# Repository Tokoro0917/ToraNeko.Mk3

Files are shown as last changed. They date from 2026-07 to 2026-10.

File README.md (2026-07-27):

# ToraNeko.Mk3

マイクロマウス（ハーフサイズクラス）ToraNeko の3代目機体（Mk3）のソフトウェア・ハードウェア（回路）・機構設計をまとめて管理するリポジトリです。
KOGUMA（クラシックサイズ機）とは別系譜の機体です。前身の KOGUMA.Mk3 系リポジトリはソフトウェアのみを対象としていましたが、本リポジトリでは
回路図・基板データ・配線資料なども含めて一元管理し、ソフトとハードの変更履歴を紐付けて追跡できるようにします。

ロボットの詳細な概要・仕様は [docs/overview.md](./docs/overview.md) を参照してください。

## ディレクトリ構成

```
.
├── software/    # マイコン・PC側ソフトウェア一式
├── hardware/    # 回路図・基板データ（KiCadプロジェクト）・BOM
├── mechanical/  # 機構部品・3Dモデル・図面
└── docs/        # 配線図、仕様書、設計メモ、議事録などのドキュメント
```

各ディレクトリの詳細は、それぞれの README.md を参照してください。

## 設計データの管理方針

- 回路・基板設計は [KiCad](https://www.kicad.org/) を使用します。プロジェクト一式は `hardware/kicad/` 以下にサブシステムごとのディレクトリを作って格納します。
- ソフトウェアは `software/` 以下にサブシステム・マイコンボードごとのディレクトリを作って格納します。
- 既存の KOGUMA.Mk3 のソフトウェア資産は、必要になったタイミングで個別に移行するかを検討します（現時点では未移行）。

## ライセンス

このリポジトリは [MIT License](./LICENSE) の下で公開されます。

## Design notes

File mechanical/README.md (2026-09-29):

# mechanical/

機構部品・筐体・3Dモデル・図面など、機械設計に関するデータを格納します。

## 構成の考え方

パーツ・アセンブリ単位、もしくはサブシステム単位でディレクトリを分けて配置してください。例:

```
mechanical/
├── frame/         # 車体・フレーム
├── drive-unit/    # 駆動系機構
└── exported/      # 発注・共有用に書き出したSTEP/STL等
```

`jigs/` には製作用の治具を置いています（[エンコーダはんだ付け治具](./jigs/encoder_solder_jig/)）。

CADツールは **Fusion 360** を使用しています。

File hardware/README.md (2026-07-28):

# hardware/

回路・基板の設計データを格納します。設計ツールは [KiCad](https://www.kicad.org/) を使用します。

## 構成の考え方

基板（プロジェクト）ごとにディレクトリを分けて `hardware/kicad/` 以下に配置してください。例:

```
hardware/
├── kicad/
│   ├── TORANEKO.Mk3/
│   ├── motor-driver-board/
│   └── sensor-board/
└── datasheets/    # 使用部品のデータシートPDF（型番横断で一元管理）
```

使用部品のデータシートは [datasheets/](./datasheets/) にまとめています。

各プロジェクトディレクトリには、KiCad のプロジェクト一式（`.kicad_pro` / `.kicad_sch` / `.kicad_pcb` など）に加えて、
以下も一緒に管理することを推奨します。

- `BOM.csv`（部品表）
- `README.md`（基板の役割、電源電圧、コネクタ・ピンアサインの概要）
- 発注用に出力したガーバー・ドリルデータ（`fab-output/` 等のサブディレクトリにまとめる）

## 運用メモ

- 基板データが大きくなってきた場合は Git LFS の導入を検討します（現時点では未導入）。
- 回路変更とそれに対応するソフトウェア変更は、可能な限り同じコミット/PRで紐付けてください。

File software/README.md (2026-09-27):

# software/

ToraNeko.Mk3 のソフトウェア一式を格納します。

## 構成の考え方

サブシステムやマイコンボードごとにディレクトリを分けて配置してください。例:

```
software/
├── main-controller/   # メイン基板（例: STM32等）のファームウェア
├── motor-driver/      # モータドライバ基板のファームウェア
└── pc-tools/          # デバッグ・調整用のPC側ツール
```

## 既存資産について

KOGUMA.MkIIl のファームウェアを参照用として `reference/koguma-mkiil/` に取り込みました。メイン基板のファームウェアは、これを参照しながら `main-controller/` に一つずつ実装していきます。

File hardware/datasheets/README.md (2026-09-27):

# hardware/datasheets/

使用部品のデータシートPDFを格納する場所です。リンク切れやメーカーサイトの仕様変更に備えて、
実際に使う部品のデータシートはPDFの実体をここに置いておきます。

## アップロード方法

1. メーカーまたは販売代理店（DigiKey/Mouser/RSなど）のサイトからPDFをダウンロードする
2. ファイル名は `<型番>.pdf` とする（例: `NCR321PAS.pdf`）
3. GitHubのWeb UIでこのディレクトリにドラッグ＆ドロップでアップロード、またはローカルにcloneしてpushする

## 部品一覧

| 型番 | 用途 | メーカー | 参考リンク | PDF |
|---|---|---|---|---|
| STM32F411CEU6 | MCU | STMicroelectronics | https://www.st.com/en/microcontrollers-microprocessors/stm32f411ce.html | 未アップロード |
| MP6551 | モータドライバ | Monolithic Power Systems | https://www.monolithicpower.com/en/mp6551.html | 未アップロード |
| NFP-D0812-1-3.7 | ブラシ付きDCモータ | - | - | 未アップロード |
| LSM6DSRXTR | IMU（ジャイロ/加速度） | STMicroelectronics | https://www.st.com/en/mems-and-sensors/lsm6dsrx.html | 未アップロード |
| AS5047P | 磁気式エンコーダ | ams OSRAM | https://ams-osram.com/products/sensor-solutions/position-sensors/ams-as5047p-high-resolution-position-sensor | 未アップロード |
| LTR-209 | 壁センサ受光（フォトトランジスタ） | Lite-On | - | 未アップロード |
| OSI5FU3A11C | 壁センサ発光（IR LED、3mm、940nm） | Optosupply | https://www.optosupply.com/uppic/20241121109582.pdf | [OSI5FU3A11C.pdf](OSI5FU3A11C.pdf)（VER A.0） |
| NCR321PAS | 壁センサLEDドライバ（定電流） | Nexperia | https://assets.nexperia.com/documents/data-sheet/NCR320PAS_NCR321PAS.pdf | [NCR321PAS.pdf](NCR321PAS.pdf)（NCR320PAS と共通、Rev.1 2020-05-13） |
| LXDC55FAAA-203 | 3.3Vレギュレータ | - | - | 未アップロード |

「参考リンク」が空欄の部品は型番からの検索が必要です。分かる方はこのテーブルに追記してください。

## 備考

- この実行環境（Claude Code on the web）はアウトバウンド通信が許可ドメインのみに制限されているため、
  Claude自身がこれらのPDFを取得してアップロードすることはできません。人手でのアップロードが必要です。

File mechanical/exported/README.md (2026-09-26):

# mechanical/exported/

Fusion 360 から書き出した共有用データ（STEP等）を置いています。

## TORANEKO.Mk3_v36.step

機体全体のアセンブリ（Fusion 360 のトップコンポーネント「全体」v36、単位mm）。

主な構成部品:

| 区分 | 部品 |
|---|---|
| 基板 | 基板（メイン基板）、上部固定基板、エンコーダ基板 × 2 |
| 駆動系 | NFP-D0812 モータ × 2、モータマウント × 2、ピニオンギア m0.3 11T × 2、平歯車 m0.3 41T × 2（減速比 41/11 ≒ 3.73）、ベアリング LF-630 × 4、3×6 平行ピン × 2 |
| 足回り | ホイール × 2、ミニッツタイヤ × 2 |
| エンコーダ | 3mm 磁石 × 2（エンコーダ基板上の AS5047P で検出） |
| 壁センサ | センサホルダ × 4、3mm 砲丸LED × 4 |
| 吸引 | 吸引ファン Φ30（アクリル）、吸引ファンモータマウント |
| 電源 | ヤシの木バッテリー 100mAh × 2 |
| その他 | 支柱 |

基板外形のDXFは `hardware/kicad/TORANEKO.Mk3/` にあります。

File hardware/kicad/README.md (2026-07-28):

# hardware/kicad/

KiCad プロジェクトを基板（サブシステム）ごとにディレクトリを分けて配置してください。

例:

```
kicad/
├── TORANEKO.Mk3/
│   ├── TORANEKO.Mk3.kicad_pro
│   ├── TORANEKO.Mk3.kicad_sch
│   ├── TORANEKO.Mk3.kicad_pcb
│   ├── BOM.csv
│   └── README.md
└── motor-driver-board/
    └── ...
```

## 現在のプロジェクト

- [TORANEKO.Mk3/](./TORANEKO.Mk3/) — メイン基板（1枚基板・全機能統合）。KiCadプロジェクト作成済み（現状は空、これから回路図を起こす）。機能ブロック・ペリフェラル割り当て案・BOMドラフトも同ディレクトリに格納。

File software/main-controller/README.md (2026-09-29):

# main-controller

ToraNeko.Mk3 メイン基板（STM32F411CEU6）のファームウェアです。

KOGUMA.MkIIl のコード（[../reference/koguma-mkiil/](../reference/koguma-mkiil/)）を参照しつつ、機能ごとに内容を確認しながら一つずつ実装していきます。
確認・実装が済んだものだけをこのディレクトリに置きます。

- [PIN_REQUIREMENTS.md](PIN_REQUIREMENTS.md): 確定したピン割り当て（回路図から抽出）と、KOGUMA との違い
- [CUBEMX_SETUP.md](CUBEMX_SETUP.md): CubeMX（`.ioc`）の設定値（ステップ0）

## 決定事項

| 項目 | 決定 | 理由・補足 |
|---|---|---|
| 書き込み・デバッグ | STLINK-V3MODS（SWD） | SWDIO=PA13, SWCLK=PA14, NRST。SWO（PB3）は任意 |
| PCとの通信・printf | UART → STLINK-V3MODS の仮想COMポート | 書き込みとログがケーブル1本で済む。**USBは使わない**（PA11/PA12 を他用途に回せる） |
| UART | USART1（PA9 TX / PA10 RX）を推奨 | APB2 側なので高速化しやすい。PA2/PA3（USART2）は ADC 入力と取り合いになるため避ける |
| 開発環境 | STM32CubeIDE | KOGUMA と同じ。ピン・クロック設定は `.ioc`（CubeMX）で管理 |
| ライブラリ | STM32 HAL | 1kHz 割り込み内で重い箇所は、必要になったら LL/レジスタ直接に置き換える |
| プロジェクト名 | `TORANEKO.Mk3` | KiCad プロジェクトと揃える |
| クロック | HSE 水晶 10MHz → SYSCLK 100MHz | PLL: M=5, N=200, P=4（VCO 400MHz）。APB1=50MHz、APB2=100MHz、タイマークロックは全て100MHz。USBを使わないので48MHzは不要 |
| 制御周期 | **2kHz**（`config/robot_params.h` の `CTRL_FREQ_HZ` で変更可能にする） | 処理時間の見積りは CPU 使用率 約10〜18%。実機で余裕を測り、余裕があれば 4kHz（壁センサは 2kHz のまま）に上げる。PID ゲイン等は周期から換算する作りにする |
| 制御周期のタイマー | TIM11 | ピンを使わない内部タイマー |
| 壁センサの点灯・測定の順番制御 | TIM3 で ADC を起動し、DMA 完了割り込みで次の LED に進める連鎖方式 | CPU を待たせずに 4 組を毎周期測定できる（2組ずつ同時点灯なので連鎖全体で約 100µs）。詳細はステップ6 |
| 処理時間計測・µs 待ち | TIM5（32bit）を 1MHz でフリーラン | 制御割り込みの開始・終了時刻を記録して CPU 使用率を常に確認できるようにする |
| ms 単位の待ち | SysTick（`HAL_GetTick()`） | KOGUMA の「共通カウンタを 0 に戻す `wait_ms`」はやめる |
| 割り込み優先度 | 壁センサの連鎖（ADC の DMA）> 制御周期（TIM11）> ログ送信（USART の DMA） | 制御処理が長引いてもセンサ測定が遅れないようにする |
| ファイル構成・命名規則 | 下記「ファイル構成」「命名規則」の通り | 生成コードと自作コードを分離し、自作コードは層ごとにフォルダ分け |

## ファイル構成

```
software/main-controller/
├── README.md                     決定事項・ファイル構成・実装ステップ（このファイル）
├── PIN_REQUIREMENTS.md           ピン割り当ての論点
│
└── TORANEKO.Mk3/                 CubeIDE プロジェクト
    ├── TORANEKO.Mk3.ioc          CubeMX 設定（ピン・クロック・周辺機能）
    ├── .project / .cproject      CubeIDE のプロジェクト設定（生成）
    ├── STM32F411CEUX_FLASH.ld    リンカスクリプト（生成）
    │
    ├── Core/                     ── CubeMX が生成。USER CODE 欄以外は編集しない
    │   ├── Inc/
    │   │   ├── main.h            ピン名の定義（.ioc のラベルから生成）
    │   │   ├── adc.h  dma.h  gpio.h  spi.h  tim.h  usart.h
    │   │   ├── stm32f4xx_it.h
    │   │   └── stm32f4xx_hal_conf.h
    │   ├── Src/
    │   │   ├── main.c            初期化のあと app_init() / app_loop() を呼ぶだけ
    │   │   ├── adc.c  dma.c  gpio.c  spi.c  tim.c  usart.c   周辺機能の初期化
    │   │   ├── stm32f4xx_it.c    割り込みの入口（処理は App 側を呼ぶだけ）
    │   │   ├── stm32f4xx_hal_msp.c
    │   │   ├── system_stm32f4xx.c
    │   │   ├── syscalls.c        printf の出力先を UART に向ける
    │   │   └── sysmem.c
    │   └── Startup/
    │       └── startup_stm32f411ceux.s
    │
    ├── Drivers/                  ── HAL / CMSIS（生成・編集しない）
    │
    ├── App/                      ── 自作コードはすべてここ
    │   ├── app.c / app.h         app_init()、app_loop()。全体の入口
    │   │
    │   ├── config/               機体の定数
    │   │   ├── robot_params.h    タイヤ径、ギア比、トレッド幅、制御周期など
    │   │   └── ctrl_gains.h      PID ゲイン、フィードフォワード係数
    │   │
    │   ├── drv/                  ハードに直接触れる層（HAL を呼ぶのはここだけ）
    │   │   ├── encoder.c/.h      AS5047P ×2：角度の読み取り
    │   │   ├── imu.c/.h          LSM6DSR：角速度・加速度の読み取り
    │   │   ├── motor.c/.h        MP6551 ×2：PWM の出力（電圧を指定）
    │   │   ├── wall.c/.h         壁センサ：LED を2組ずつ点灯し、AD 値を読む
    │   │   ├── battery.c/.h      バッテリ電圧の読み取り
    │   │   ├── fan.c/.h          吸引ファンの PWM
    │   │   ├── led.c/.h          UI 用 LED
    │   │   ├── buzzer.c/.h       ブザー
    │   │   └── uart.c/.h         ログ送信（DMA 送信・リングバッファ）
    │   │
    │   ├── ctrl/                 制御
    │   │   ├── odometry.c/.h     エンコーダと IMU から速度・距離・角度を求める
    │   │   ├── pid.c/.h          汎用の PID 計算
    │   │   ├── trajectory.c/.h   台形加減速などの目標速度の生成
    │   │   ├── wall_ctrl.c/.h    壁のあり・なし判定、壁に沿った姿勢の補正
    │   │   └── run.c/.h          直進・スラローム・斜めなどの動作
    │   │
    │   ├── maze/                 迷路（HAL に依存しない。PC でテストできる）
    │   │   ├── maze_map.c/.h     壁の情報の保持・更新・保存
    │   │   ├── search.c/.h       足立法・歩数マップ・行き止まり潰し
    │   │   └── path.c/.h         最短経路（ダイクストラ）と、経路の圧縮・斜めへの変換
    │   │
    │   └── sys/                  全体の管理
    │       ├── scheduler.c/.h    1kHz の周期処理（センサ → 制御 → 出力の順に呼ぶ）
    │       ├── mode.c/.h         走行モードの選択と実行
    │       ├── ui.c/.h           モード選択の操作、LED・ブザーでの通知
    │       ├── log.c/.h          走行ログの記録と吸い出し
    │       ├── failsafe.c/.h     異常の検知（衝突、電圧低下など）と停止
    │       └── flash.c/.h        迷路・パラメータの Flash への保存
    │
    └── test/                     ── PC 上で動かすテスト（CI で実行）
        ├── test_maze.c           迷路探索・最短経路のテスト
        └── Makefile
```

### 層の依存関係

```
sys  →  ctrl / maze  →  drv  →  HAL（Core/, Drivers/）
```

- 呼び出しは上の層から下の層への一方向のみ。`drv` から `ctrl` を呼ぶような逆向きの呼び出しはしない
- HAL を直接呼ぶのは `drv/` と `sys/scheduler.c`（タイマー割り込みの起動）だけ
- `maze/` は `drv` も HAL も使わない。PC 上でそのままテストできる
- `Core/` 側の生成コードには、USER CODE 欄に `App/` の関数呼び出しを1行書くだけにする（CubeMX で再生成しても自作コードが消えないように）

## 命名規則

| 対象 | 規則 | 例 |
|---|---|---|
| ファイル名 | 小文字＋アンダースコア。層はフォルダで表し、ファイル名には付けない | `drv/encoder.c`, `ctrl/pid.c` |
| 関数名 | `モジュール名_動詞_目的語`（小文字＋アンダースコア） | `encoder_read_angle()`, `motor_set_voltage()` |
| 型名 | 小文字＋アンダースコア＋`_t` | `pid_ctrl_t`, `odometry_state_t`（`pid_t` は標準ライブラリと衝突するので使わない） |
| ファイルをまたぐ変数 | `g_` を付ける（なるべく使わず、関数経由で受け渡す） | `g_maze_map` |
| ファイル内だけの変数・関数 | `static` を付ける | `static float s_prev_error;` |
| 定数・マクロ | 大文字＋アンダースコア | `MAZE_SIZE`, `CTRL_PERIOD_S` |
| インクルードガード | `ファイルパスを大文字に_H` | `DRV_ENCODER_H` |

## 実装の進め方

各ステップで「KOGUMA の該当コードを読む → ToraNeko で変える点を決める → 実装 → 実機/PCで確認」を行います。

| # | 内容 | 作るファイル | KOGUMA側の対応ファイル | 状態 |
|---|---|---|---|---|
| 0 | F411 用の空プロジェクト作成（CubeIDE、クロック設定） | `.ioc`, `Core/`, `App/app.c` | `KOGUMA.MkIIl.ioc` | 設定値決定済み（[CUBEMX_SETUP.md](CUBEMX_SETUP.md)）。プロジェクト作成待ち |
| 1 | LED点灯とシリアル出力（printf） | `drv/led.c`, `drv/uart.c` | `UI.c`, `syscalls.c` | 未着手 |
| 2 | 2kHz 制御周期割り込み | `sys/scheduler.c` | `PL_timer.c` | 未着手 |
| 3 | エンコーダ読み取り（AS5047P） | `drv/encoder.c` | `PL_encoder.c` | 未着手 |
| 4 | IMU 読み取り（LSM6DSR） | `drv/imu.c` | `lsm6dsr.c` | 未着手 |
| 5 | モータ PWM | `drv/motor.c` | `motor.c`（出力部分） | 未着手 |
| 6 | 壁センサ（2組ずつ点灯） | `drv/wall.c`, `ctrl/wall_ctrl.c` | `PL_sensor.c`, `Wallsensor.c` | 未着手 |
| 7 | 速度・角度制御（PID、フィードフォワード） | `ctrl/odometry.c`, `ctrl/pid.c`, `ctrl/trajectory.c`, `ctrl/run.c` | `motor.c`, `Move.c` | 未着手 |
| 8 | 迷路探索と最短経路 | `maze/*`, `test/` | `Maze.c` | 未着手（PCでテスト可） |
| 9 | 走行モード、ログ、フェイルセーフ、保存 | `sys/mode.c`, `sys/ui.c`, `sys/log.c`, `sys/failsafe.c`, `sys/flash.c` | `main.c`, `UI.c`, `LOG.c`, `Failsafe.c` | 未着手 |

### KOGUMA のファイルとの対応

| KOGUMA | ToraNeko |
|---|---|
| `PL_encoder.c` | `drv/encoder.c` |
| `lsm6dsr.c` | `drv/imu.c` |
| `PL_sensor.c` | `drv/wall.c`（LED点灯・AD読み取り）、`drv/battery.c` |
| `Wallsensor.c` | `ctrl/wall_ctrl.c` |
| `motor.c` | `drv/motor.c`（PWM出力）、`ctrl/pid.c`、`ctrl/odometry.c`、`drv/fan.c` |
| `Move.c` | `ctrl/trajectory.c`、`ctrl/run.c` |
| `Maze.c` | `maze/maze_map.c`、`maze/search.c`、`maze/path.c` |
| `PL_timer.c` | `sys/scheduler.c` |
| `main.c`（モード選択部分） | `sys/mode.c` |
| `UI.c` | `sys/ui.c`、`drv/led.c`、`drv/buzzer.c` |
| `LOG.c` | `sys/log.c` |
| `Failsafe.c` | `sys/failsafe.c` |
| `Define.h` | `config/robot_params.h`、`config/ctrl_gains.h` |

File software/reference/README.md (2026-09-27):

# reference/

参照用に取り込んだ過去の機体のソフトウェアです。**ここのコードは編集しません。**
ToraNeko.Mk3 用の実装は `../main-controller/` で行います。

| ディレクトリ | 元リポジトリ | コミット | 備考 |
|---|---|---|---|
| `koguma-mkiil/` | [Tokoro0917/KOGUMA.MkIIl](https://github.com/Tokoro0917/KOGUMA.MkIIl) | `e456da38832444fc30eb78e9e4e20f32978636c6`（2026-09-25） | STM32F446RE 向け。旧版 `KOGUMA.MkII/` と `.github/` は除外 |

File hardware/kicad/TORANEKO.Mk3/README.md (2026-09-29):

# TORANEKO.Mk3

ToraNeko.Mk3 のメイン基板（1枚基板・全機能統合、基板一体型シャーシ）のKiCadプロジェクトです。

KiCadプロジェクト本体（`TORANEKO.Mk3.kicad_pro` / `.kicad_sch` / `.kicad_pcb`）を作成済みです（現状は空、これから回路図を起こしていきます）。
このディレクトリには、実際に回路図を起こす前に固めておいた機能ブロック構成・ペリフェラル割り当て案・BOMドラフトも一緒に置いています。

## 機能ブロック

| ブロック | 内容 |
|---|---|
| MCU | STM32F411CEU6 |
| モータドライバ | MP6551 × 2（左モータ用・右モータ用） |
| モータ | NFP-D0812-1-3.7（ブラシ付きDC）× 2 |
| エンコーダ | AS5047P（磁気式）× 2、左右モータ軸に取り付け |
| IMU | LSM6DSRXTR |
| 壁センサ | 反射型IR。受光: LTR-209、発光: OSI5FU3A11C、LEDドライバ: **NCR321PAS**（定電流・PWM対応）。前方斜め左右2組・側面左右2組の計4組 |
| 吸引ファン | サクションファン × 1（型番未定）。NチャネルMOSFETによるローサイドPWM駆動 |
| 電源 | 2セルLiPo入力 → MCU/センサ用3.3V系（**LXDC55FAAA-203**）、モータドライバ（MP6551）はLiPo直結 |
| デバッグ/書き込み | STLINK-V3MODS（SWD＋仮想COMポート）。USBは使わない |
| クロック | HSE 水晶 10MHz → SYSCLK 100MHz |

## ペリフェラル割り当て案（STM32F411CEU6）

正確なピン番号はKiCadで回路図を起こす際にデータシート（UFQFPN48パッケージ）で確定してください。
ここではどのペリフェラルをどのブロックに割り当てるかの方針のみ示します。

- **SPIバス（IMU・エンコーダ用）**: LSM6DSRXTR、AS5047P × 2 は共通SPIバス上にCS（チップセレクト）を分けて接続する案。SPIバスを分割するかは配線の都合で判断。
- **PWM（モータ駆動用）**: MP6551 × 2 に対し、1モータあたり2本（IN1/IN2、もしくはPWM+DIR）を想定。TIM1などの高機能タイマーを優先的に割り当てる。
- **ADC（壁センサ用）**: LTR-209（受光）× 4組ぶんでADC 4チャンネル（PA3〜PA6）を使用。OSI5FU3A11C（発光）側は **NCR321PAS**（LED 1個につき1個）の VEN を GPIO 2本で2組ずつ駆動する（組A: PB0、組B: PA7）
- **PWM（吸引ファン用）**: MOSFETゲート駆動用に1チャンネル。モータ駆動用タイマーとは別チャンネルを割り当てる。
- **UART（ログ出力）**: USART1（PA9 TX / PA10 RX）を STLINK-V3MODS の仮想COMポートに接続する案。USBは使わないので PA11/PA12 は他用途に使える。
- **SWD**: STLINK-V3MODS での書き込み・デバッグ用に PA13（SWDIO）/ PA14（SWCLK）/ NRST を確保。SWO（PB3）は任意。

## 電源設計メモ

- 入力: 2セルLiPo（7.4V公称、満充電8.4V程度）
- MCU/センサ系: 3.3Vへ降圧、**LXDC55FAAA-203** を使用
- 壁センサLEDドライバ（NCR321PAS）: **3.3V系から給電（決定）**。センサ周りにバッテリ電圧（変動する電圧）を持ち込まないため。LED 1個につき NCR321PAS 1個、**ピーク約 155mA** のパルス点灯。回路は下記「壁センサ発光回路」を参照
- モータ系: LiPoをレギュレータを介さず**MP6551に直結**（MP6551の定格電圧範囲内であることを確認済みとして進める）
- 吸引ファン系: LiPoから供給、MOSFETでPWM制御（レギュレータを挟むかはファン選定後に確定）

## 壁センサ発光回路

LED 1個につき NCR321PAS 1個（×4組）。発光制御の GPIO は2本で、1本の GPIO で2個の VEN を同時に駆動する（組A: PB0 → IC3/D7 と IC8/D9、組B: PA7 → IC4/D8 と IC9/D10）。組み合わせは **組A = 左前向き＋右向き、組B = 右前向き＋左向き**。横向きの2組は光軸が機体中央で交差する（クロス配置）が、別の組なので同時には点かない。同時に点く2組は向きが反対なので干渉しにくい。ただし同じ組の2個は機体の同じ側に並ぶ（右向きは左側に付いて右を向くため）ので、LED からの光が隣の受光素子に直接入らないよう、センサホルダで遮光する。

2個同時点灯なのでピーク電流は約 310mA（155mA × 2）。大容量コンデンサの電圧降下も2倍になり、NCR321PAS の電圧余裕は最悪で 1.4V をわずかに下回る見込み。足りない場合は電流が少し下がる（暗くなる）だけなので、実測で確認する。

```
【電源部：4組で共通】

 +3V3 ──[FB1]──┬──────────┬───────────── 3V3_LED（LED1〜4のアノードへ）
 (MCU系)        │          │
            C1,C2 ═╧═      C3 ═╧═ 0.1µF
         47µF×2 │          │
                 GND        GND

【発光部：1組分（×4組）】

 3V3_LED
    │
    ▼  D1  OSI5FU3A11C（1: アノード、2: カソード）
    │
  ┌─┴──────────────── U1 NCR321PAS ──┐
  │  6: IOUT / 7: IOUT（裏面パッド）  │
  │  1: VEN ◄───────┬──────── GPIO（組A: PB0 / 組B: PA7、1本で2個の VEN を駆動）
  │                R2 100kΩ           │
  │                 │                 │
  │                GND                │
  │  2: REXT ──[R1 5.1Ω 1%]── GND     │
  │  5: GND ───────────────── GND     │
  │  3, 4, 8: N/C                     │
  └───────────────────────────────────┘
```

| 記号 | 部品 | 値 | 数 | 備考 |
|---|---|---|---|---|
| D1 | 赤外LED | OSI5FU3A11C | 4 | 940nm。IF=100mA で VF typ 1.35V / max 1.6V。パルス最大 1000mA（100µs, 1/100） |
| U1 | 定電流ドライバ | NCR321PAS | 4 | DFN2020D-6 |
| R1 | Rext | 5.1Ω 1% | 4 | 約 155mA（データシート Fig.16/17 の 4Ω≒190mA、6Ω≒135mA から 1/Rext で補間）。E96 の 4.99Ω なら約 160mA。センサごとに差し替え可能なよう 0603/0805 |
| R2 | VEN プルダウン | 100kΩ | 4 | リセット中（GPIO 入力状態）に LED が点かないようにする |
| FB1 | フェライトビーズ | 0603、定格 300mA 以上、DCR 0.1Ω 以下 | 1 | 0Ω でも可。MCU・ADC 側の 3.3V にパルス電流を流さないため |
| C1, C2 | バルクコンデンサ | 47µF 10V X5R 1206 | 2 | DC バイアス込みで実効 100µF 程度を確保。ドライバ直近 |
| C3 | デカップリング | 0.1µF | 1 | ドライバ直近。4組が離れる場合は各ドライバに追加 |

### 設計上の注意

- **VEN は GPIO から直結**（直列抵抗を入れない）。EN 電圧で出力電流が変わる（Fig.24）ため。VEN の絶対最大定格は 4.5V
- **NCR321PAS の裏面パッド（7ピン）は IOUT。GND ではない。** GND ベタにつなぐと LED が常時点灯になる。LED カソードと同じネットにし、放熱用に銅箔を確保する
- 電圧余裕（155mA 時の見積り）: 3.3V − C1,C2 電圧降下（約 31mV: 155mA × 20µs / 100µF）− FB1（約 16mV）− VF（推定 typ 1.65V / 最悪 1.8V）= **typ 約 1.6V / 最悪 約 1.45V**。NCR321PAS の最小オーバーヘッド 1.4V を満たす（180mA〔4.3Ω〕だと最悪で約 1.4V とぎりぎりになるため、安定性を優先して 5.1Ω とした）
  - このため **1回の点灯時間は 10〜20µs** を目安にする（ソフト側で調整）
  - 余裕が足りない場合は電流が設定値より下がる（暗くなる）だけで、壊れはしない。ただし明るさが温度で変わりやすくなる
- パルス電流のループ（C1,C2 → LED → U1 → R1 → GND → C1,C2）を小さくし、受光側・ADC 入力の近くを通さない
- 側面センサは壁が近く、受光側が飽和する可能性がある。実測で距離と AD 値の関係を確認し、必要ならセンサごとに Rext を変える（例: 側面は 9.1Ω≒100mA）

## 部品配置ガイド（DXF）

機体全体の STEP（`mechanical/exported/TORANEKO.Mk3_v36.step`）から、配置の目安になる DXF を生成したもの。KiCad の PCB エディタで「ファイル → インポート → グラフィック」から `User.Drawings` などのレイヤーに読み込み、ガイド内の基板外形（レイヤー `00_BOARD`）が既存の Edge.Cuts に重なるように置く。

### `配置ガイド_メイン基板.dxf`（上から見た図。`メイン基板外形.dxf` と同じ座標系）

| レイヤー | 内容 |
|---|---|
| `00_BOARD` | メイン基板外形（位置合わせ用） |
| `10_ENC_BOARD` | エンコーダ基板が立つ位置（6 × 0.6mm）と中心線 |
| `11_ENC_CHIP` | AS5047P の位置（エンコーダ基板の外側＝磁石側の面） |
| `12_MAGNET_AXIS` | 磁石（Φ3）と回転軸の線 |
| `20_CONTACT` | 基板面（z=0.65mm）で切った断面＝基板に接する部品の足元（モータマウント、センサホルダ、支柱、ホイール、41T ギア） |
| `30_OVERHANG` | 基板の上に浮いている部品の外形（破線）。ラベルの値は基板上面からの隙間＝その下に置ける部品の高さの上限 |

基板上面からの隙間（この高さ未満の部品なら下に置ける）:

| 部品 | 隙間 |
|---|---|
| モータ NFP-D0812 | 1.25mm |
| ベアリング LF-630 | 1.01mm |
| 吸引ファンモータ MK06-45 | 2.00mm |
| 平行ピン 3×6 / 磁石 | 3.11mm |
| ピニオン 11T | 3.36mm |
| 吸引ファンモータマウント | 4.98mm |

### エンコーダ基板の位置（KiCad 座標）

現在のメイン基板外形の取り込み位置（DXF 原点 → KiCad (96.5, 61.05)）で換算した値。

| | エンコーダ基板が立つ範囲 | 中心 | AS5047P（チップ）がある側 | 磁石 |
|---|---|---|---|---|
| 右（機体右、非ミラー側） | X 118.257〜118.857、Y 63.05〜69.05 | (118.557, 66.05) | +X 側（X 118.81〜120.00） | X 120.5〜121.5 |
| 左（機体左、ミラー側） | X 100.943〜101.543、Y 63.05〜69.05 | (101.243, 66.05) | −X 側（X 99.80〜100.99） | X 98.3〜99.3 |

- 磁石の回転軸は Y = 66.05、メイン基板上面から高さ 4.61mm
- エンコーダ基板は高さ 8.5mm、厚さ 0.6mm（STEP 上）。AS5047P と磁石の隙間は 0.5mm

### `配置ガイド_エンコーダ基板.dxf`（エンコーダ基板を磁石側から見た図。`エンコーダ外形.dxf` と同じ座標系）

- 上端（y = 0.513）がメイン基板にはんだ付けされる辺
- 磁石の軸（Φ1 の円）はメイン基板から 4.61mm。AS5047P はこの軸に中心を合わせ、フットプリントを 90° 回して置く（ピンの列が上下に来る向き）
- AS5047P のパッドから基板端までは、メイン基板側 0.94mm、反対側 0.21mm（反対側は製造ルールの最小クリアランスを要確認）
- `30_EDGE_PAD_ZONE`: メイン基板とはんだ付けするエッジパッドを置ける範囲。裏面（チップのない面）は幅いっぱいに 0.79mm、チップ面は同じ 0.79mm の帯か、左右の角（0.68 × 1.3mm）

## エンコーダ接続用フットプリント（`TORANEKO_Encoder.pretty/`）

エンコーダ基板（6 × 8.5 × 0.6mm）をメイン基板に垂直に立て、はんだで接続するためのフットプリント。左右のエンコーダ基板は同じ設計のまま使える（180° 回して置くだけ）。

| フットプリント | 使う部品 | 原点 | パッド |
|---|---|---|---|
| `TN_ENC_Edge` | エンコーダ基板側（U3, U5） | はんだ付けする辺の中央。+Y が基板の奥（メイン基板から離れる向き） | 1〜4（MOSI, MISO, SCK, CS）: 裏面、幅 0.9mm、ピッチ 1.4mm、辺から 0.2〜1.2mm。5〜6（VCC, GND）: チップ面、幅 2.0mm、辺から 0.2〜0.72mm（AS5047P のパッドと 0.2mm 以上離す） |
| `TN_ENC_Base` | メイン基板側（U4, U6） | エンコーダ基板が立つ位置の中央。−Y がチップ側 | 1〜4: 裏面側の列、5〜6: チップ側の列。エンコーダ基板の面（中心から ±0.3mm）から外へ 1.0mm |

- `TN_ENC_Edge` の `Dwgs.User` に、磁石の軸（辺から 4.613mm）と AS5047P の外形（5.0 × 4.4mm）を描いてある。AS5047P はその中心に合わせ、90° 回して置く
- `TN_ENC_Base` の置き方（回転は KiCad の角度）:

| | 位置 | 回転 |
|---|---|---|
| 右エンコーダ（U4 か U6、チップが +X 向き） | (118.557, 66.05) | 270° |
| 左エンコーダ（チップが −X 向き） | (101.243, 66.05) | 90° |

- エンコーダ基板は小さいため、基板端クリアランス（基板のセットアップ → 制約 → 銅箔から基板端）は **0.2mm** にする（0.5mm だと AS5047P のパッドとエッジパッドが違反になる。AS5047P のパッドは上端から 0.22mm）
- ライブラリの追加: 設定 → フットプリントライブラリの管理 → プロジェクト固有のライブラリ に `${KIPRJMOD}/TORANEKO_Encoder.pretty` を追加

## TODO

- [x] SPIバスの分割方針 → IMU は SPI1（PB3/4/5）、エンコーダは SPI2（PB13/14/15）に分割
- [x] モータPWM用タイマー・チャンネルの確定 → TIM4 CH1〜CH4（PB6〜PB9）
- [ ] NCR321PASの電流設定抵抗値の実測確認: **Rext = 5.1Ω（1%、約 155mA）** に決定。実機で電流・IOUT 電圧（1.2V 以上残っているか）・温度による AD 値の変化を確認
- [ ] NCR321PASの3.3V系での電圧マージン実測確認（155mA 時の見積りは typ 約1.6V / 最悪 約1.45V。OSI5FU3A11C の 155mA 時 VF はデータシートに記載がないため実測が必要）
- [ ] LXDC55FAAA-203 の出力電流に LED パルス分（最大約 155mA、同時点灯1個）の余裕があるか確認
- [ ] 吸引ファンの型番選定
- [ ] 吸引ファン用MOSFET・ゲート抵抗・フライホイールダイオードの選定
- [ ] 吸引ファンの電源系統（LiPo直結か別レギュレータか）の判断
- [x] 正式なピンアサイン表の作成 → `software/main-controller/PIN_REQUIREMENTS.md`（回路図 `9a54a18` から抽出）
- [ ] 各部品のシンボル・フットプリントをライブラリに追加し、回路図に配置

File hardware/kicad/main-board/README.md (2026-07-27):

# main-board

ToraNeko.Mk3 のメイン基板（1枚基板・全機能統合、基板一体型シャーシ）です。

KiCadプロジェクト本体（`.kicad_pro` / `.kicad_sch` / `.kicad_pcb`）はまだKiCad上で作成していません。
このディレクトリには、実際に回路図を起こす前に固めておく機能ブロック構成・ペリフェラル割り当て案・BOMドラフトを置いています。

## 機能ブロック

| ブロック | 内容 |
|---|---|
| MCU | STM32F411CEU6 |
| モータドライバ | MP6551 × 2（左モータ用・右モータ用） |
| モータ | NFP-D0812-1-3.7（ブラシ付きDC）× 2 |
| エンコーダ | AS5047P（磁気式）× 2、左右モータ軸に取り付け |
| IMU | LSM6DSRXTR |
| 壁センサ | 反射型IR。受光: LTR-209、発光: OSI5FU3A11C、LEDドライバ: **NCR321PAS**（定電流・PWM対応）。前方斜め左右2組・側面左右2組の計4組 |
| 吸引ファン | サクションファン × 1（型番未定）。NチャネルMOSFETによるローサイドPWM駆動 |
| 電源 | 2セルLiPo入力 → MCU/センサ用3.3V系（**LXDC55FAAA-203**）、モータドライバ（MP6551）はLiPo直結 |
| デバッグ/書き込み | SWD、USB（STM32F411CEU6のUSB OTG FSを想定） |

## ペリフェラル割り当て案（STM32F411CEU6）

正確なピン番号はKiCadで回路図を起こす際にデータシート（UFQFPN48パッケージ）で確定してください。
ここではどのペリフェラルをどのブロックに割り当てるかの方針のみ示します。

- **SPIバス（IMU・エンコーダ用）**: LSM6DSRXTR、AS5047P × 2 は共通SPIバス上にCS（チップセレクト）を分けて接続する案。SPIバスを分割するかは配線の都合で判断。
- **PWM（モータ駆動用）**: MP6551 × 2 に対し、1モータあたり2本（IN1/IN2、もしくはPWM+DIR）を想定。TIM1などの高機能タイマーを優先的に割り当てる。
- **ADC（壁センサ用）**: LTR-209（受光）× 4組ぶんでADC 4チャンネルを使用。OSI5FU3A11C（発光）側は **NCR321PAS**（定電流LEDドライバ、デジタルPWM入力対応・最大10kHz）のPWM/イネーブル入力用に4本のGPIOを確保し、1組ずつ順番に点灯・測定して隣接センサ間のクロストークを避ける。
- **PWM（吸引ファン用）**: MOSFETゲート駆動用に1チャンネル。モータ駆動用タイマーとは別チャンネルを割り当てる。
- **USB**: PA11/PA12（USB OTG FS）をデバッグ・書き込み・ログ出力用に確保する想定。
- **SWD**: ST-Link等での書き込み・デバッグ用に確保。

## 電源設計メモ

- 入力: 2セルLiPo（7.4V公称、満充電8.4V程度）
- MCU/センサ系: 3.3Vへ降圧、**LXDC55FAAA-203** を使用
- 壁センサLEDドライバ（NCR321PAS）: 3.3V系から給電。OSI5FU3A11Cの順方向電圧＋NCR321PASのオーバーヘッド1.4Vを考慮すると余裕は大きくないため、電流設定抵抗値と実測での電流マージン確認が必要（TODO）
- モータ系: LiPoをレギュレータを介さず**MP6551に直結**（MP6551の定格電圧範囲内であることを確認済みとして進める）
- 吸引ファン系: LiPoから供給、MOSFETでPWM制御（レギュレータを挟むかはファン選定後に確定）

## TODO

- [ ] SPIバスの分割方針（IMUとエンコーダを同一バスにするか）
- [ ] モータPWM用タイマー・チャンネルの確定
- [ ] NCR321PASの電流設定抵抗値の決定（OSI5FU3A11Cの目標駆動電流から算出）
- [ ] NCR321PASの3.3V系での電圧マージン実測確認
- [ ] 吸引ファンの型番選定
- [ ] 吸引ファン用MOSFET・ゲート抵抗・フライホイールダイオードの選定
- [ ] 吸引ファンの電源系統（LiPo直結か別レギュレータか）の判断
- [ ] 正式なピンアサイン表の作成（KiCad回路図と同期）
- [ ] KiCadプロジェクトの作成（`.kicad_pro` / `.kicad_sch` / `.kicad_pcb`）

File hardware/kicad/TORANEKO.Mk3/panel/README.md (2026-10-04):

# 発注用パネル（エンコーダ基板 ×6 ＋ 上部固定基板 ×1）

エンコーダ基板（6 × 8.5 × 0.6mm）6 枚（IC5 側 ×3、IC7 側 ×3）と、上部固定基板（25.75 × 26.8 × 0.6mm、銅箔なし）1 枚を並べた発注用パネル。メイン基板とは別の注文で出す。

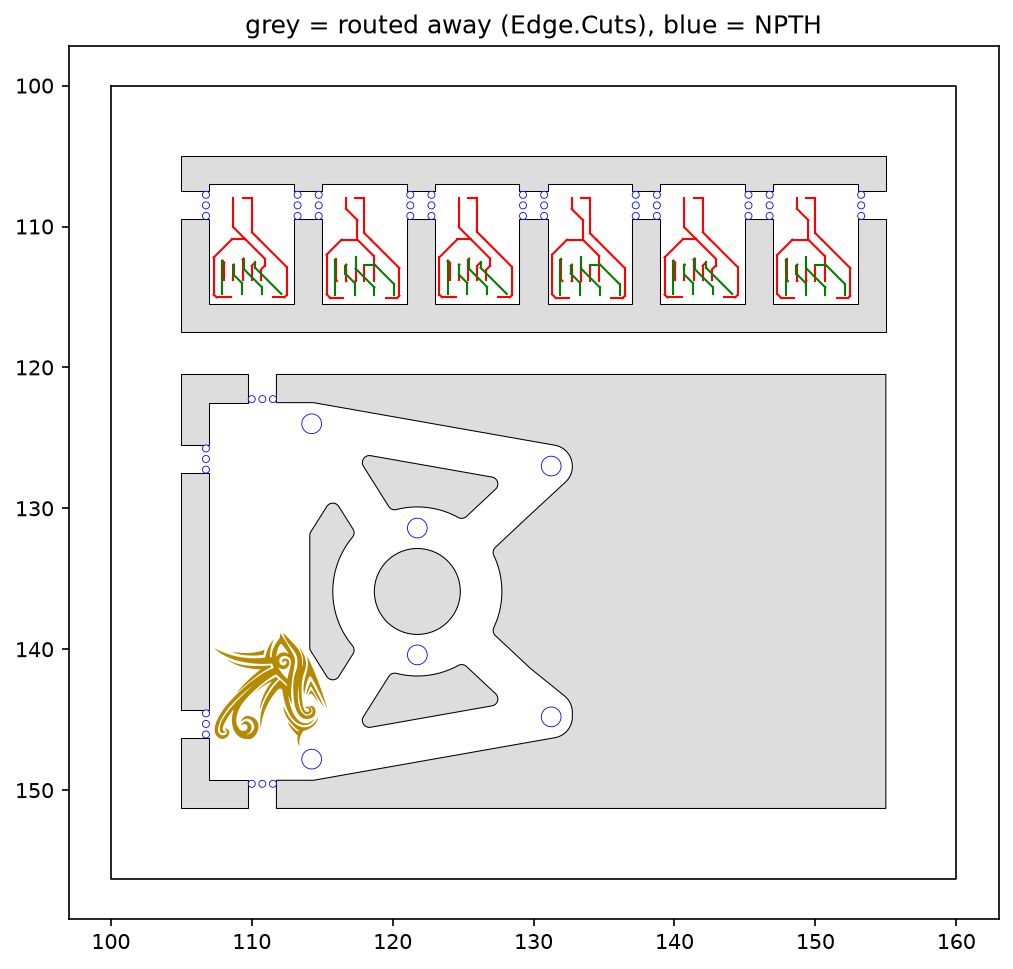
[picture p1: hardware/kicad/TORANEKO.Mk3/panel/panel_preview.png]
パネル


| 項目 | 値 |
|---|---|
| パネル寸法 | 60 × 56.3mm（枠 5mm、基板間・枠との隙間 2mm、上下の段の間に幅 3mm の桟） |
| ミシン目 | NPTH Φ0.5mm、ピッチ 0.75mm、1 か所 3 穴。穴は基板の外側（タブ側）に置き、折ったあとの残りは基板の外に出る |

## エンコーダ基板（上の段）

| 項目 | 値 |
|---|---|
| 基板の固定 | 左右の辺のタブ（上端から 0.5〜2.5mm、幅 2mm）＋ミシン目 |
| はんだ付けする辺（下辺） | タブなし。ルーターで切るのできれいな辺になる |
| 上辺 | タブなし（AS5047P のパッドまで 0.22mm しかないため） |

- ミシン目の穴から銅箔までは 0.8mm 以上
- パネル内の各コピーは別のネット名（`_2`, `_3` 付き）にしてあるので、DRC で「未接続」は出ない

## 上部固定基板（下の段）

| 項目 | 値 |
|---|---|
| 外形 | `../上部固定基板外形.dxf` から読み込み（円弧は 2µm 以下の誤差で折れ線にしている） |
| 基板の固定 | まっすぐな辺だけにタブ（幅 2mm）: 左辺 ×2、上下の短い直線辺 ×1 ずつ。曲線の辺にはタブを付けない |
| 内側の抜き | 3 か所の抜きと Φ6.1 の穴は Edge.Cuts、Φ1.4 の穴 ×6 は NPTH |
| ロゴ | `../ロゴ_ホワイトグリント.dxf` を F.SilkS に塗りつぶしで配置（左下の空き、右に 90° 回転、幅 8.0mm）。外形・抜き・穴から 0.3mm 離して入る最大の大きさをスクリプトが自動で決める |

- DXF（y 上向き）を KiCad（y 下向き）に変換しているので、パネル上では DXF を上下反転した向きになる。銅箔のない板なので、裏返せば同じ形
- ロゴは 8mm と小さいため、線の 1 割ほどがシルクの最小線幅（0.15mm）より細い。細い先端や線の間の隙間は、印刷でつぶれたり欠けたりすることがある
- 左辺のタブの跡（ミシン目のバリ）が組み付けに当たる場合は、やすりで落とす

## 作り直し方

メイン基板（`../TORANEKO.Mk3.kicad_pcb`）のエンコーダ部分や `../上部固定基板外形.dxf` を修正したら、次で作り直す。

```bash
python3 make_panel.py
```

- 必要なライブラリ: `shapely`、`ezdxf`
- メイン基板上でエンコーダ基板を移動した場合も、`BOARDS` の外形の座標を直す（部品の相対位置が同じなら他は不要）
- エンコーダ基板の外形の位置（スクリプト内の `BOARDS`）が変わった場合は、そこも直す
- 上部固定基板の上下のタブ位置は、DXF の直線辺（x = -7.25〜0.13）の中央に決め打ちしている。外形を変えたらスクリプトの `utab_x0` を確認する

## 発注時の設定（JLCPCB の例）

- Panel by Customer（自分で面付け済み）、V-Cut なし
- 厚さ 0.6mm、2 層
- ガーバーは KiCad でこのファイルを開いて出力する

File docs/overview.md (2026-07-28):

# ToraNeko.Mk3 概要

## これは何か

マイクロマウス（ハーフサイズクラス）の機体です。マイクロマウス公式規格に準拠します。

## 前世代機・関連機体との関係

- KOGUMA（クラシックサイズ機）とは別系譜の機体です。ToraNeko はハーフサイズを一貫して開発しているシリーズで、本機は3代目（Mk3）にあたります。
- 探索・走行アルゴリズムは KOGUMA でブラッシュアップした内容をベースに、ToraNeko Mk3 に引き継ぎます。

## 目標大会

- 次の目標大会: **北信越大会**（ハーフサイズクラス）
- 詳細な開催日程・レギュレーション詳細は別途確認（TODO）

## ハードウェア仕様

### マイコン

- STM32F411CEU6

### 駆動系

- モータ: ブラシ付きDCモータ **NFP-D0812-1-3.7** × 2（左右）
- モータドライバ: **MP6551**（1chあたり1個、左右で2個）。電源はLiPoからレギュレータを介さず直結
- タイヤ径: 14mm
- ギア比などの詳細は未定（TODO）

### 吸引ファン（サクション）

- 走行中の路面吸着力向上のため、吸引ファンを搭載する
- 駆動方式: PWM可変速（NチャネルMOSFETによる片側ローサイドドライブ）。ファンは回転方向固定のためHブリッジ不要
- ファンの具体的な型番は未定（TODO、候補選定中）

### センサ

- 壁センサ: 反射型IR、受光 **LTR-209** + 発光 **OSI5FU3A11C** × 4組（前方斜め左右2組・側面左右2組）、LEDドライバ **NCR321PAS**（定電流・PWM対応、3.3V系から給電）
- 姿勢センサ（ジャイロ/IMU）: **LSM6DSRXTR**
- エンコーダ: 磁気式エンコーダIC **AS5047P** × 2（左右モータ軸）

### 電源

- 2セル（7.4V系）LiPoバッテリーを想定
- 3.3Vレギュレータ: **LXDC55FAAA-203**（MCU/センサ系）

### 筐体・シャーシ

- 1枚基板に全機能を統合する基板一体型シャーシ
- 吸引ファンのための気密シール（スカート）が必要（TODO）
- 具体的な層構成・材質は未定（TODO）

回路設計の詳細（機能ブロック・ペリフェラル割り当て案・BOMドラフト・KiCadプロジェクト）は
[hardware/kicad/TORANEKO.Mk3/](../hardware/kicad/TORANEKO.Mk3/) を参照してください。

## ソフトウェア

- KOGUMA で改良した迷路探索アルゴリズムを ToraNeko.Mk3 向けに移植・調整する
- 詳細な設計（探索方式、最短経路再構築、走行制御のパラメータなど）は別途 `software/` 配下で管理

## TODO / 未定事項

- [ ] 北信越大会の開催日程・詳細レギュレーションの確認（吸引ファンの使用可否・レギュレーションも要確認）
- [ ] モータのギア比・タイヤ幅など駆動系の詳細
- [ ] 吸引ファンの型番選定
- [ ] 吸引ファン用スカート（気密シール）の設計
- [ ] 基板一体型シャーシの層構成・材質
- [ ] KOGUMA からの迷路アルゴリズム移植範囲の整理

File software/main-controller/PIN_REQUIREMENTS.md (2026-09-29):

# ピン割り当て（ToraNeko.Mk3 確定版）と KOGUMA.MkIIl との対応

ToraNeko.Mk3 メイン基板（STM32F411CEU6, UFQFPN48）の確定したピン割り当てと、KOGUMA.MkIIl（STM32F446RE）との違いをまとめたものです。
CubeMX の具体的な設定値は [CUBEMX_SETUP.md](CUBEMX_SETUP.md) を参照。

## ToraNeko.Mk3 の確定ピン割り当て

回路図 `hardware/kicad/TORANEKO.Mk3/TORANEKO.Mk3.kicad_sch`（コミット `d0b5a54`）から抽出。

| ピン番号 | ピン | 回路図のネット名 | 用途 | 周辺機能（AF） | CubeMX ラベル案 |
|---|---|---|---|---|---|
| 2 | PC13 | - | 未使用 | - | - |
| 3 | PC14 | - | 未使用 | - | - |
| 4 | PC15 | ENCO-R-NSS | 右エンコーダ CS | GPIO 出力（低速のみ可） | `ENC_R_CS` |
| 5 / 6 | PH0 / PH1 | - | 10MHz セラミック発振子（CSTNE10M0G52Z000R0） | RCC_OSC_IN / OUT | - |
| 7 | NRST | NRST | リセット（J6） | - | - |
| 10 | PA0 | LED7 | 表示LED7 | GPIO 出力 | `LED7` |
| 11 | PA1 | FunPWM | 吸引ファン PWM（Q5 ゲート） | TIM2_CH2（AF1） | - |
| 12 | PA2 | BATT | バッテリ電圧（100k/47k 分圧、C24 0.1µF） | ADC1_IN2 | - |
| 13 | PA3 | Wallsen-4 | 壁センサ受光4 | ADC1_IN3 | - |
| 14 | PA4 | Wallsen-3 | 壁センサ受光3 | ADC1_IN4 | - |
| 15 | PA5 | Wallsen-2 | 壁センサ受光2 | ADC1_IN5 | - |
| 16 | PA6 | Wallsen-1 | 壁センサ受光1 | ADC1_IN6 | - |
| 17 | PA7 | WallLED-2 | 壁センサ発光 組B: 右前向き＋左向き（IC4/D8 と IC9/D10 の VEN を同時駆動） | GPIO 出力 | `WALL_LED_B` |
| 18 | PB0 | WallLED-1 | 壁センサ発光 組A: 左前向き＋右向き（IC3/D7 と IC8/D9 の VEN を同時駆動） | GPIO 出力 | `WALL_LED_A` |
| 19 | PB1 | LED6 | 表示LED6 | GPIO 出力 | `LED6` |
| 20 | PB2 | LED5 | 表示LED5（BOOT1 兼用。BOOT0=Low なので影響なし） | GPIO 出力 | `LED5` |
| 21 | PB10 | LED4 | 表示LED4 | GPIO 出力 | `LED4` |
| 25 | PB12 | LED3 | 表示LED3 | GPIO 出力 | `LED3` |
| 26 | PB13 | ENCO-SCK | エンコーダ SPI SCK | SPI2_SCK（AF5） | - |
| 27 | PB14 | ENCO-MISO | エンコーダ SPI MISO | SPI2_MISO（AF5） | - |
| 28 | PB15 | ENCO-MOSI | エンコーダ SPI MOSI | SPI2_MOSI（AF5） | - |
| 29 | PA8 | ENCO-L-NSS | 左エンコーダ CS | GPIO 出力 | `ENC_L_CS` |
| 30 | PA9 | UART-TX | ログ出力（STLINK-V3MODS 仮想COMポートへ） | USART1_TX（AF7） | - |
| 31 | PA10 | LED2 | 表示LED2 | GPIO 出力 | `LED2` |
| 32 | PA11 | LED1 | 表示LED1 | GPIO 出力 | `LED1` |
| 33 | PA12 | - | ユーザースイッチ SW1（押すと High、R9 10k プルダウン） | GPIO 入力 | `SW_USER` |
| 34 | PA13 | SWDIO | SWD | SYS_JTMS-SWDIO | - |
| 37 | PA14 | SWCLK | SWD | SYS_JTCK-SWCLK | - |
| 38 | PA15 | IMU-NSS | IMU CS | GPIO 出力 | `IMU_CS` |
| 39 | PB3 | IMU-SCK | IMU SPI SCK | SPI1_SCK（AF5） | - |
| 40 | PB4 | IMU-MISO | IMU SPI MISO | SPI1_MISO（AF5） | - |
| 41 | PB5 | IMU-MOSI | IMU SPI MOSI | SPI1_MOSI（AF5） | - |
| 42 | PB6 | PWML-1 | 左モータ MP6551 IN1 | TIM4_CH1（AF2） | - |
| 43 | PB7 | PWML-2 | 左モータ MP6551 IN2 | TIM4_CH2（AF2） | - |
| 44 | BOOT0 | - | R8 10k で GND | - | - |
| 45 | PB8 | PWMR-1 | 右モータ MP6551 IN1 | TIM4_CH3（AF2） | - |
| 46 | PB9 | PWMR-2 | 右モータ MP6551 IN2 | TIM4_CH4（AF2） | - |

### KOGUMA.MkIIl との違い（ソフトの修正点）

| 機能 | KOGUMA.MkIIl | ToraNeko.Mk3 | ソフトへの影響 |
|---|---|---|---|
| モータ PWM | TIM3 CH1〜4 | **TIM4 CH1〜4** | `htim3` → `htim4`。チャンネル割り当て（左 CH1/2、右 CH3/4）は同じ |
| 吸引ファン PWM | TIM2 CH1 | **TIM2 CH2** | チャンネル番号のみ変更 |
| ブザー | TIM4 CH4 | **なし** | ブザー関連コードは移植しない |
| 制御周期割り込み | TIM6 | **TIM11（案、検討中）** | F411 に TIM6 がないため |
| IMU | SPI1（PA5〜7）、CS=PA4 | **SPI1（PB3〜5）**、CS=PA15 | ハンドルは同じ `hspi1`。CS ピンのみ変更 |
| エンコーダ | SPI3、CS=PC5/PA15 | **SPI2**、CS=PA8/PC15 | `hspi3` → `hspi2` |
| 壁センサ受光 | ADC1 IN10〜13 | **ADC1 IN3〜6** | チャンネル番号を変更。DMA バッファの並び（[0]=バッテリ、[4]=センサ1）は同じにできる |
| バッテリ電圧 | ADC1 IN9、分圧 10k/47k | **ADC1 IN2、分圧 47k/100k** | 換算式を `× (100+47)/47` に変更 |
| 壁センサ発光 | GPIO 2本（2組ずつ同時点灯） | **GPIO 2本（2組ずつ同時点灯）**。ただし LED 1個ごとに NCR321PAS 1個 | 点灯の順番は KOGUMA と同じ2段。ピンと組み合わせだけ変更 |
| 表示LED | 12個 | **7個** | UI 表示を作り直す |
| シリアル | USART2 半二重（PA2）115200bps | **USART1 TX のみ（PA9）** | `huart2` → `huart1` |
| スイッチ | - | **PA12 ×1** | モード選択の操作を1ボタン＋エンコーダ等で設計（ステップ9） |

## 参考: KOGUMA.MkIIl（STM32F446RE）での割り当て

| 機能 | 周辺機能 | ピン | 使用箇所 | 備考 |
|---|---|---|---|---|
| 左モータ PWM | TIM3 CH1 / CH2 | PC6 / PC7 | `motor.c` | 1モータ2本（IN1/IN2 方式）。ARR=200 |
| 右モータ PWM | TIM3 CH3 / CH4 | PC8 / PC9 | `motor.c` | 同上 |
| 吸引ファン PWM | TIM2 CH1 | PB8 | `motor.c`, `main.c` | ARR=100 |
| ブザー PWM | TIM4 CH4 | PB9 | `UI.c`, `main.c` | |
| 制御周期割り込み（1kHz） | TIM6 | - | `PL_timer.c` | |
| IMU（LSM6DSR） | SPI1 | PA5 SCK / PA6 MISO / PA7 MOSI | `lsm6dsr.c` | CS は `ICM_NSS`（PA4）。名前は旧IMU（ICM）の名残 |
| エンコーダ（AS5047P ×2） | SPI3 | PC10 SCK / PC11 MISO / PB0 MOSI | `PL_encoder.c` | CS は `ENCO_L_NSS`（PC5）/ `ENCO_R_NSS`（PA15） |
| バッテリ電圧 | ADC1 IN9 | PB1 | `PL_sensor.c` | DMAバッファ `g_ADCBuffer[0]` |
| 壁センサ受光 ×4 | ADC1 IN10〜IN13 | PC0〜PC3 | `PL_sensor.c` | `g_ADCBuffer[1..4]`。DMA（DMA2 Stream0 CH0） |
| 壁センサ発光 | GPIO ×2 | PA1 `WallLED_12` / PA0 `WallLED_34` | `PL_sensor.c` | 2組ずつ同時点灯 |
| UI LED | GPIO ×12 | PB12〜15, PB4〜7（LED1〜8）、PA3, PC13〜15（LEDF1〜4） | `UI.c` | |
| シリアル（printf） | USART2 半二重 | PA2 | `syscalls.c` | 115200bps |
| 書き込み・デバッグ | SWD | PA13 / PA14 | | |
| 外部クロック | HSE 10MHz | PH0 / PH1 | | SYSCLK 180MHz |
| 未使用のGPIO出力 | | PA10 / PA11 / PA12 | | 用途なし（初期化のみ） |

## STM32F411CEU6 へ移すときの論点（回路図作成前の検討メモ。結論は上の確定表）

| 項目 | 問題 | 対応案 |
|---|---|---|
| クロック | 最大 100MHz（F446 は 180MHz） | クロック設定と全タイマーの分周値を再計算。HSE の周波数も回路で確定する |
| モータ PWM | PC6〜PC9 は48ピン版に存在しない | TIM3 CH1〜4 を PA6/PA7/PB0/PB1 か PB4/PB5/PB0/PB1 に割り当てれば `motor.c` は無修正。ただし PA6/PA7 は SPI1 と、PB0/PB1 は ADC と競合するので注意。TIM1 CH1〜4（PA8〜PA11）に移すなら `htim3` → `htim1` の置換と MOE 設定が必要。PA11 は USB と競合 |
| 制御周期割り込み | F411 に TIM6 がない | TIM5 / TIM9 / TIM10 / TIM11 のいずれかで代用（`PL_timer.c` と割り込みハンドラを修正） |
| エンコーダ SPI | PC10/PC11 が存在しない | SPI2（PB13/PB14/PB15）か、SPI3 を PB3/PB4/PB5 に割り当て。IMU と同じ SPI1 に相乗りも可（その場合 `hspi3` → `hspi1`） |
| 壁センサ ADC | PC0〜PC3 が存在しない。F411 の ADC 入力は PA0〜PA7, PB0, PB1 の10本のみ | 受光4ch＋バッテリ電圧1ch の計5本を PA0〜PA7/PB0/PB1 から確保。SPI1（PA5〜PA7）と取り合いになるので要検討 |
| 壁センサ発光 | ToraNeko は NCR321PAS ×4 で1組ずつ点灯する計画（KOGUMA は2本で2組ずつ） | GPIO（またはPWM）4本を確保。`PL_sensor.c` の点灯シーケンスを4段に書き換える |
| UI LED | 12本は48ピンでは厳しい | 本数を減らすか、LEDドライバ/シフトレジスタ等を検討。`UI.c` を合わせて修正 |
| USB | ToraNeko では PA11/PA12 を USB に使う計画 | KOGUMA では未使用なので競合なし |
| シリアル | USART2 PA2 | そのまま使える（PA2/PA3 は ADC 入力とも兼用なので取り合いに注意） |
| 吸引ファン・ブザー | TIM2 CH1（PB8 は F411 では TIM4/TIM10）、TIM4 CH4（PB9） | F411 でも TIM4 CH4 = PB9 は使える。TIM2 CH1 は PA0/PA5/PA15 のいずれか |

## 回路図完成後の照合項目

- [x] 上表の各機能に、実際に割り当てたピン・周辺機能を記入（上の確定表）
- [x] ADC 5ch が全て ADC 入力可能ピンか（PA2〜PA6 = IN2〜IN6）
- [x] タイマーのチャンネルと AF 番号（TIM4 CH1〜4 = PB6〜PB9 AF2、TIM2 CH2 = PA1 AF1）
- [x] SPI の CS ピン（IMU=PA15、エンコーダ左=PA8、右=PC15）
- [ ] MP6551 の入力方式（IN1/IN2 PWM）とソフトの PWM 出し方（`motor.c` の `200 - Motor_Voltage`）が合っているか（ステップ5で MP6551 データシートと照合）
- [x] HSE の周波数（10MHz セラミック発振子）

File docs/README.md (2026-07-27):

# docs/

ソフト・ハード・機構のいずれにも属さない横断的なドキュメントを格納します。

- [overview.md](./overview.md) — ロボット（ToraNeko.Mk3）の概要・仕様

例:

- 配線図・結線表（回路図と実配線の対応がわかる資料）
- 全体仕様書・要求仕様
- 設計メモ・検討記録・議事録
- 大会ルール等の外部資料の要約

各サブシステムに閉じた詳細ドキュメントは、対応する `hardware/` や `software/` 配下の README に置くことを優先し、
ここには複数サブシステムにまたがる資料を置いてください。

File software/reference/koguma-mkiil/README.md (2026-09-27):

# KOGUMA MkIIl

STM32F446RE(STM32CubeIDE)をベースにしたマイクロマウス(迷路探索ロボット)のファームウェア。

## ハードウェア

- MCU: STM32F446RE(Cortex-M4, Flash 512KB, RAM 128KB)
- 開発環境: STM32CubeIDE 1.14.0

## ディレクトリ構成

```
Core/Src, Core/Inc   本体ファームウェア
Drivers/             STM32 HAL / CMSIS
KOGUMA.MkII/          旧バージョン一式(参考用に同梱)
test/                ホスト(PC)上で走る迷路アルゴリズムのテスト
.github/workflows/   CI設定
*.ioc                STM32CubeMX設定
STM32F446RETX_*.ld   リンカスクリプト
```

`Debug/`(ビルド成果物)とホストテストの実行ファイルは`.gitignore`で除外している。

## 迷路探索アルゴリズム(`Core/Src/Maze.c`)

2種類の最短経路計算を実装:

- **`Maze_Shortest_Calculation()`**: セル単位のBFS歩数マップに基づく最短経路。直交移動のみ。
- **`Maze_Dijkstra_Calculation()`**: 半セル(壁境界)単位のグラフ上でSPFA(キューベースのBellman-Ford)を用いたダイクストラ法。直進・斜め・コーナー継続でコストを変え(`ST_COST`/`DIAG_COST`/`CON_COST`)、斜め走行を積極的に使う経路を生成する。

どちらも生成した手順を`Shortest_Pass_Compression()` → `Shortest_Pass_Compression_NANAME()`で圧縮し、コーナーの大廻り・斜め入り/出のパターンに変換してから`Move.c`のモーター制御関数(`Short_NANAME_Move*`/`Short_Dijkstra_Move2000`など)が実行する。

ゴールは迷路中央の2×2区画(標準ルール)。どの面が開口になっているか大会では事前に分からないため、ゴール判定(BFS・ダイクストラとも)は2×2区画を囲む境界のどこから侵入しても「到達」とみなすようになっている。

### 行き止まり潰し(`Maze_DeadEnd_Fill()`)

確認済みの壁だけで出入口が1つ以下になったマスは、入った辺と同じ辺からしか出られないため、そのマス自身が始点/終点でない限り最短経路上に絶対に乗らない。エセ全面探索(ALL_MODE)は未探索マスを片端から目標にするので、放っておくとこうした袋小路のポケットにも寄り道してしまう。

`Maze_DeadEnd_Fill()`はそういうマスを`G_MAZE_Closed[][]`に記録し、**連鎖させる**。1マス閉じるとそのマスは隣にとって「出口」として数えられなくなるので、袋小路の通路が根元まで一気に潰れる。`Maze_Gool_Setting()`は閉鎖マスを全面探索の目標候補から外す。

呼び出しは`Maze_Wall_Update()`の4方向分岐、`Maze_Step_Calculate()`の直前。

安全側に倒すための作りが要点:

| 方針 | 理由 |
|---|---|
| `G_Maze_Row`/`G_Maze_Column`(実測の壁マップ)を書き換えない | マップの保存・表示・ダイクストラは今まで通り真の壁だけを見る |
| 閉鎖情報を歩数マップBFSの通行判定に使わない。使うのは目標選定だけ | 誤って閉じても起きるのは「そのマスを探索しない」だけ。経路が塞がる/帰還できなくなる経路が構造的に存在しない |
| 毎回ゼロから再計算(ステートレス) | 誤った閉鎖が累積しない。探索用⇔帰還用のゴール切り替えにも自動追従 |
| 未確認の壁は「開いている」とみなす | 既知の壁 ⊆ 真の壁 なので、探索途中の部分知識では完全知識より必ず閉鎖数が少なくなる |
| スタート・現在の目標・ゴール2×2区画は閉じない | スタートは初期状態で3枚壁。守らないと即座に潰れて帰還できなくなる |

`G_DeadEnd_Fill_Enable`を`0`にすると実行時に無効化でき、従来動作に戻る。閉鎖したマス数は`g_deadend_closed_count`で確認できる(`Maze_Mapping()`内にコメントアウト済みの可視化用printfあり)。

副次的な効果として、壁で完全に囲まれた到達不能マスは出入口0で必ず閉鎖されるため、ALL_MODEが通常の「未探索マス数が0」の経路でクリーンに終了するようになった(従来は「自分のマスがMAX_STEPのまま」を検出するフォールバック頼みだった。フォールバック自体は保険として残してある)。

### 迷路サイズ

`Core/Inc/Define.h`の`MAZE_SIZE`(既定16)を書き換えるだけで16×16⇔32×32を切り替えられる。壁ビット幅・ノード配列サイズ・キュー容量・ゴール座標は全てこの値から自動的に導出される。

32×32時のSRAM見積り(Maze.c分のみ、実測): 16×16で約11.6KB → 32×32で約43.6KB。現在`Short_Dijkstra_Move2000`はmain.cから未接続なのでリンカに削除されており、現状のビルドサイズには影響していない。32×32を実際に有効化する場合は、`Core/Src/LOG.c`の`LOG_MAX`(現在2000、既定3000から削減済み)を含めたRAM予算の再確認が必要。

## メイン動作モード(`Core/Src/main.c`)

ロータリーエンコーダの`Encorder_mode_out()`(モード)と`Encorder_number_out()`(ナンバー)の組み合わせで動作を選択する。

### モード0: 大会用(探索走行)

いずれも「往路: スタート→ゴール」「復路: ゴール→スタート」の2区間を走り、各区間の終わりで`Maze_Save()`する。

| No | 往路/復路の走り方 | 全面探索 | 復路後の最短走行 |
|---|---|---|---|
| 1 | スラローム探索 | **あり**(復路で実施) | なし |
| 2 | スラローム探索 | なし | なし |
| 3 | 吸引探索 | なし | なし |
| 4 | 吸引探索 | **あり**(復路で実施) | なし |
| 5 | 吸引探索 | なし | あり(直線5000mm/s, 加速15000) |
| 6 | 既知区間加速(`Robot_Maze_Pass_Action`) | なし | あり(直線6000mm/s, 加速15000) |
| 7 | 往路: 既知区間加速 / その後: ダイクストラ誘導の未知壁探索 | なし | なし |

No.7は往路でゴールに着いたあと、スタート→ゴールのダイクストラ経路上に残っている未確認の壁を、今いる位置から直接見に行く(`Maze_Unknown_Wall_Scan()`)。経路の再計算は毎回ではなく、ゴールに着いた直後とUターンしたときだけ行う。経路上の未知壁がなくなったらスタートへ帰る。

エセ全面探索(`Maze_Unkown_ALL_ModeSet()`)が有効なのは**No.1とNo.4だけ**。他は`Maze_Unkown_ALL_ModeSet()`の呼び出しがコメントアウトされている。したがって**行き止まり潰しが走行に影響するのもこの2つだけ**で、残りのモードの挙動は導入前と変わらない(`Maze_DeadEnd_Fill()`自体は常に計算されるが、結果を使う`Maze_Gool_Setting()`の分岐がALL_MODE時にしか通らないため)。

### モード1: 最短走行(速度・アルゴリズム違い)

`Short_NANAME_Move*(MAX, AC)`の`MAX`が直線区間の最高速度、`AC`が加速度。関数名の数字はコーナー通過速度。

| No | 経路生成 | コーナー | 直線最高速 | 加速度 |
|---|---|---|---|---|
| 1 | BFS | 2000 | 6000 | 15000 |
| 2 | BFS | 2000 | 6000 | 20000 |
| **3** | **ダイクストラ**(`Short_Dijkstra_Move2000`) | 2000 | 6000 | 20000 |
| 4 | BFS | 2000 | 6000 | 25000 |
| 5 | BFS | 2000 | 6000 | 30000 |
| 6 | BFS | 2400 | 6000 | 15000 |
| 7 | BFS | 2400 | 6000 | 20000 |
| 8 | BFS | 2400 | 6000 | 23000 |
| 9 | BFS | 2700 | 5000 | 20000 |

No.2とNo.3はパラメータが同一で、BFS経路とダイクストラ経路の比較用になっている。

### モード2: サーキット
未実装

### モード3: デバッグ用(固定速度最短)

直線最高速をコーナー速度と同値にして、区間ごとの加減速を実質なくしたもの。

| No | コーナー | 直線最高速 | 加速度 |
|---|---|---|---|
| 1 | 2000 | 2000 | 20000 |
| 2 | 2400 | 2400 | 20000 |
| 3 | 2700 | 2700 | 20000 |

### モード4: 基本調整
| No | 内容 |
|---|---|
| 0 | センサ値・電圧・ジャイロのprintf表示 |
| 1 | 直進テスト |
| 2 | その場180°旋回テスト |
| 3 | スラロームテスト |
| 4 | 斜め走行テスト |
| 5 | 吸引ON+センサ待機 |
| 6 | 壁合わせ |
| 7 | ログ出力 |

### モード5〜9: 速度別 旋回パターンテスト

モード5=1.0, 6=2.0, 7=2.4, 8=2.7, 9=3.0 m/s。No.1〜7は共通で 1=90°, 2=180°, 3=in45°, 4=in135°, 5=out45°, 6=out135°, 7=V90°。

| モード | No.0 | No.1〜7 |
|---|---|---|
| 5 (1.0m/s) | 90°小回り | 実装済み |
| 6 (2.0m/s) | その場旋回(1080°) | 実装済み |
| 7 (2.4m/s) | 空 | 実装済み |
| 8 (2.7m/s) | 空 | 実装済み |
| 9 (3.0m/s) | 空 | **No.1のみ実装**、2〜7は空 |

「空」はセンサ待機だけで何も走らせない分岐。

## テストとCI

`Core/Src/Maze.c`はHALに依存しないので、ホストのgccにそのままリンクして迷路アルゴリズムを検証できる。

```sh
# 16×16
gcc -std=c11 -Wall -I Core/Inc -o test_deadend test/test_deadend.c Core/Src/Maze.c && ./test_deadend
# 32×32
gcc -std=c11 -Wall -DMAZE_SIZE=32 -I Core/Inc -o test_deadend32 test/test_deadend.c Core/Src/Maze.c && ./test_deadend32
```

`test/test_deadend.c`が行き止まり潰しについて検査する内容:

| # | 内容 |
|---|---|
| 1 | 完全迷路(全域木)200種。連鎖が根元まで効いているか、最短経路上のマスが1つも潰れていないか、スタートとゴール2×2区画が守られているか |
| 2 | ループあり迷路300種。閉鎖マスを通行不可としても最短距離が変わらないか |
| 3 | 壁を4割「未確認」に落とした探索途中の状態300種。部分知識でも同上 |
| 4 | 初期状態(外周のみ既知)で1マスも閉じないか(誤爆検出) |
| 5 | `G_DeadEnd_Fill_Enable`による有効/無効の切り替え |

1〜3では、素朴な「変化がなくなるまで全マス走査」で書いた**参照実装**と閉鎖集合が完全一致するかも突き合わせている。仕様そのものの正しさは最短距離不変の検査が、連鎖機構(ワークリストの積み忘れ・打ち切り)のバグは参照実装との一致が担保する役割分担。

テストは不変条件が壊れると非0で終了する。実際に`Maze_Cell_IsProtected()`の保護を外した改変版を通すと失敗を検出することを確認済み。

CIは`.github/workflows/maze-test.yml`で、masterへのpushとPRのときに16×16と32×32の両方を実行する。ファームウェア本体のARMビルドは対象外。

## 大会前チェック

- `Core/Inc/Define.h`の`MAZE_GOOL_X/Y`は標準ゴール(迷路中央2×2、`MAZE_SIZE/2-1`)。ベンチテストでスタート近くにゴールを置きたいときだけ一時的に書き換え、**書き換えたままコミットしないこと。** 行き止まり潰しのゴール保護もこの定数から導出している。
- `Move.c`の`Short_Dijkstra_Move2000()`終端の旋回角度(180°→270°)の調整は、手元で作業中ならリポジトリには未反映。

## 直近の主な変更

- **行き止まり潰し(`Maze_DeadEnd_Fill()`)を追加**。確認済みの壁だけで出入口が1つ以下のマスを連鎖的に閉じ、エセ全面探索の目標候補から外す。壁マップは書き換えず、通行判定にも使わないため、誤判定の最悪ケースが「そのマスを探索しない」で頭打ちになるようにしてある(詳細は上記)
- ホスト上で`Core/Src/Maze.c`を直接リンクして回すテスト(`test/test_deadend.c`)とCI(`.github/workflows/maze-test.yml`)を追加
- `Maze_Dijkstra_Calculation()`: FIFOキュー+早すぎる確定ロックによりダイクストラとして不正だった箇所をSPFA(再緩和可能なキュー)に修正
- 経路配列(`G_Short_Pass`/`_CP`/`_NANAME`)の終端が正しく0に戻されず、短い経路の後に前回の長い経路の残骸を読み進めてしまうバグを修正
- ダイクストラのゴール判定が「ゴールセルを通り抜けた奥の境界」を起点にしていたため、普通の最短(BFS)より1マス多く進んでしまうバグを修正。ゴール2×2区画を囲む8境界すべてを起点にするマルチソース方式に変更(侵入方向を問わず、区画に入った時点で停止)
- `LOG.c`の境界チェックの off-by-one(配列を1要素分オーバーランするバグ)を修正、あわせてログ長を3000→2000サンプルに削減してRAMを確保

## ビルド

ファームウェア本体はSTM32CubeIDEで本フォルダをワークスペースにインポートしてビルドする。

迷路アルゴリズムだけを手元で確かめたい場合は、上記「テストとCI」のgccコマンドでホスト上でも動かせる。

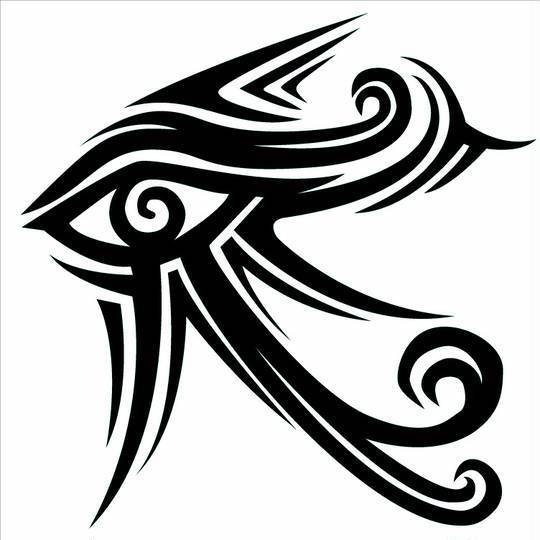
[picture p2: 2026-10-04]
hardware/kicad/TORANEKO.Mk3/ホワイトグリント色反転ロゴ.jpg

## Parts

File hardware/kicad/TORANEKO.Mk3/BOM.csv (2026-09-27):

Reference | Part | Value/PartNumber | Qty | Notes
U1 | MCU | STM32F411CEU6 | 1 | UFQFPN48
U2/U3 | Motor Driver | MP6551 | 2 | 1 per motor (left/right)
U4 | IMU | LSM6DSRXTR | 1 | SPI/I2C 6-axis
U5/U6 | Magnetic Encoder | AS5047P | 2 | 1 per motor shaft (left/right)
M1/M2 | Brushed DC Motor | NFP-D0812-1-3.7 | 2 | left/right drive
- | Tire | 14mm diameter | 2 | left/right
BT1 | Battery Connector | 2S LiPo | 1 | 7.4V nominal
- | Wall Sensor (IR emitter) | OSI5FU3A11C | 4 | 2 front-diagonal + 2 side
- | Wall Sensor (IR receiver) | LTR-209 | 4 | 2 front-diagonal + 2 side
U8/U9/U10/U11 | IR LED Driver | NCR321PAS | 4 | constant-current, digital PWM enable, 1 per emitter
R? | IR LED Driver Current-Set Resistor | 5.1 ohm 1% | 4 | Rext for NCR321PAS: ~155 mA peak (typ, interpolated from datasheet Fig.16/17); 0603/0805 so it can be swapped; verify by measurement
R? | IR LED Driver VEN Pull-down | 100k | 4 | keeps LED off while GPIO is floating (reset)
FB? | Ferrite Bead (3V3_LED branch) | 0603 >=300mA DCR<=0.1ohm | 1 | or 0 ohm; separates LED pulse current from MCU/ADC 3.3V
C? | 3V3_LED Bulk Capacitor | 47uF 10V X5R 1206 | 2 | ~100 uF effective total near the LED drivers
C? | 3V3_LED Decoupling | 0.1uF | 1 | near the LED drivers
U7 | 3.3V Regulator | LXDC55FAAA-203 | 1 | for MCU/sensors
M3 | Suction Fan | TBD | 1 | downforce - part TBD
Q1 | Fan Drive MOSFET | TBD | 1 | N-channel low-side PWM drive

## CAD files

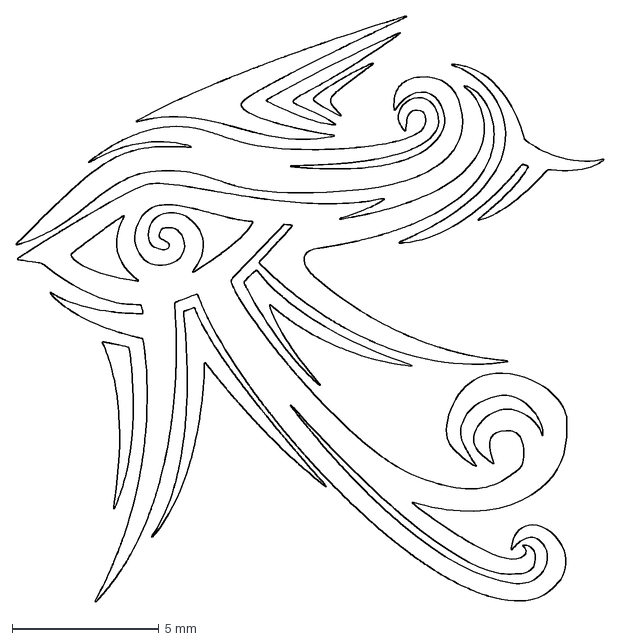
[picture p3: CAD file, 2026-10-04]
hardware/kicad/TORANEKO.Mk3/ロゴ_ホワイトグリント.dxf
20.0 x 19.9 mm

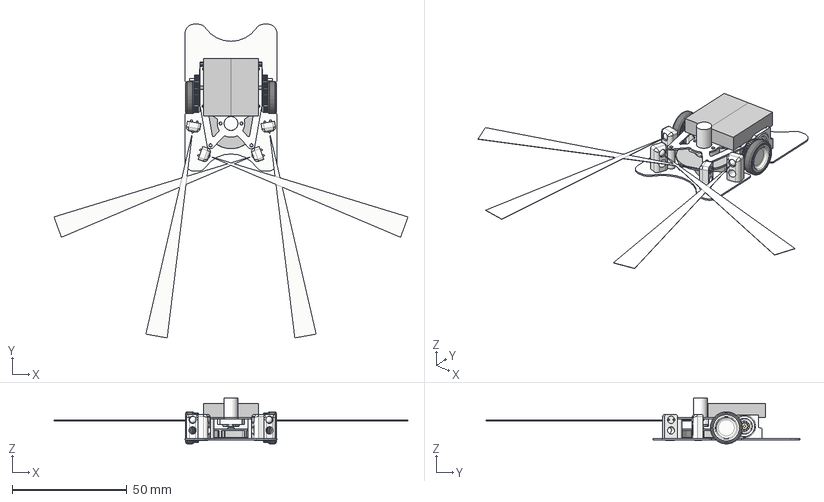
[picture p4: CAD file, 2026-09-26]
mechanical/exported/TORANEKO.Mk3_v36.step
154.1 x 136.6 x 19.8 mm
基板
NFP-D0812
Spur Gear (11 teeth)
ホイール
ミニッツタイヤ
Spur Gear (41 teeth)
3*6平行ピン
LF-630_ir x 2
LF-630_cage x 2
LF-630_ball x 16
LF-630_or x 2
3mm磁石
モータマウント
TSSOP14_OSM
Φ3弾丸型LED v2 v1 x 4
支柱 x 2
上部固定基板
NFP-D0812 v2(ミラー)
Spur Gear (11 teeth)(ミラー)
ホイール v21(ミラー)
ミニッツタイヤ v5(ミラー)
Spur Gear (41 teeth)(ミラー)
3*6平行ピン v1(ミラー)
LF-630_ir_1 x 2
LF-630_cage_1 x 2
LF-630_ball_1 x 16
LF-630_or_1 x 2
3mm磁石 v1(ミラー)
TSSOP14_OSM v1(ミラー)
モータマウント v12(ミラー)
MK06-45
吸引ファンモータマウント
ヤシの木バッテリー100mAh
ヤシの木バッテリー100mAh_1
吸引ファンΦ30内径1mm v7

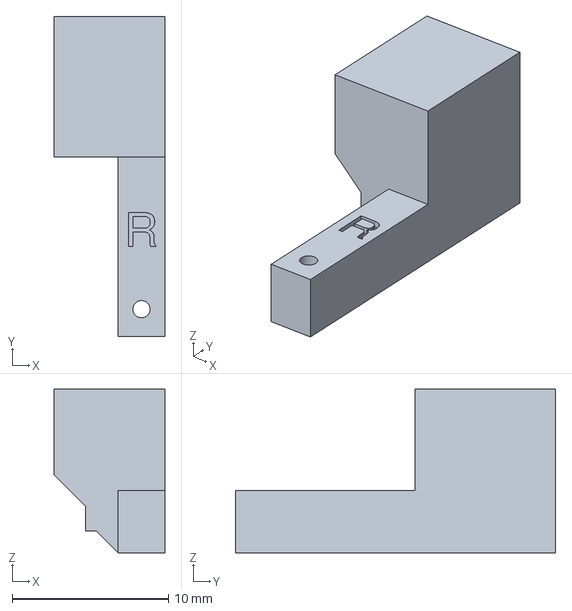
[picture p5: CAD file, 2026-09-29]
mechanical/jigs/encoder_solder_jig/encoder_jig_R.step
7.10 x 20.5 x 10.5 mm

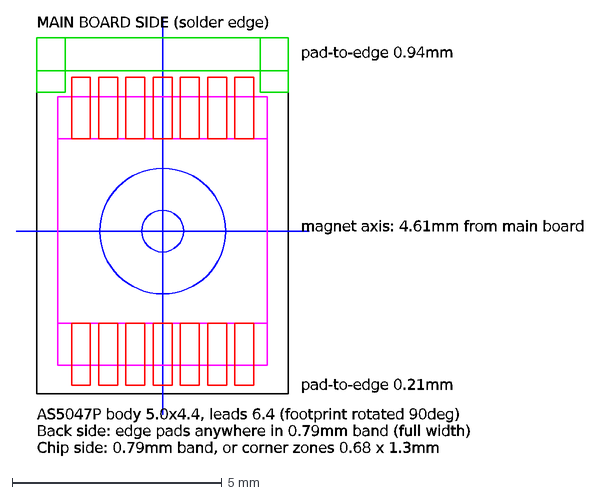
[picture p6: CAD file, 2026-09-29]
hardware/kicad/TORANEKO.Mk3/配置ガイド_エンコーダ基板.dxf
MAIN BOARD SIDE (solder edge)
pad-to-edge 0.94mm
pad-to-edge 0.21mm
magnet axis: 4.61mm from main board
AS5047P body 5.0x4.4, leads 6.4 (footprint rotated 90deg)
Back side: edge pads anywhere in 0.79mm band (full width)
Chip side: 0.79mm band, or corner zones 0.68 x 1.3mm

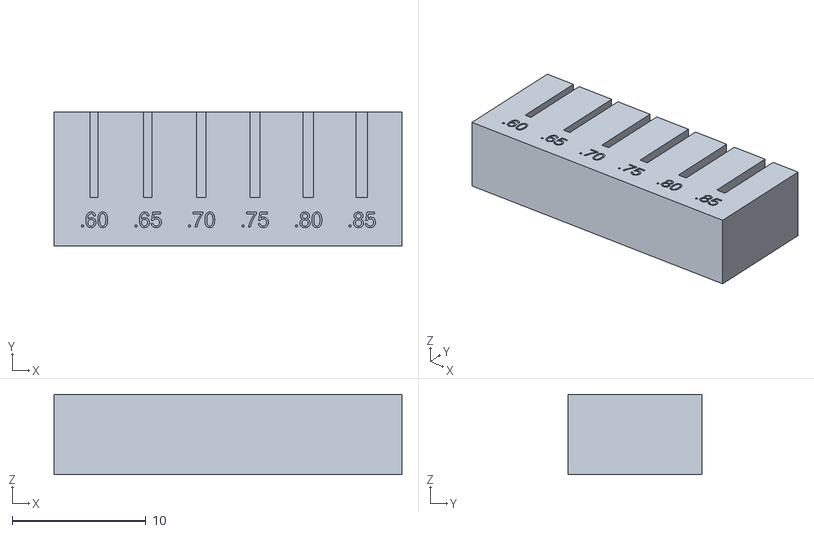
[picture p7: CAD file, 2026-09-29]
mechanical/jigs/encoder_solder_jig/slot_width_test.stl
26.0 x 10.0 x 6.00

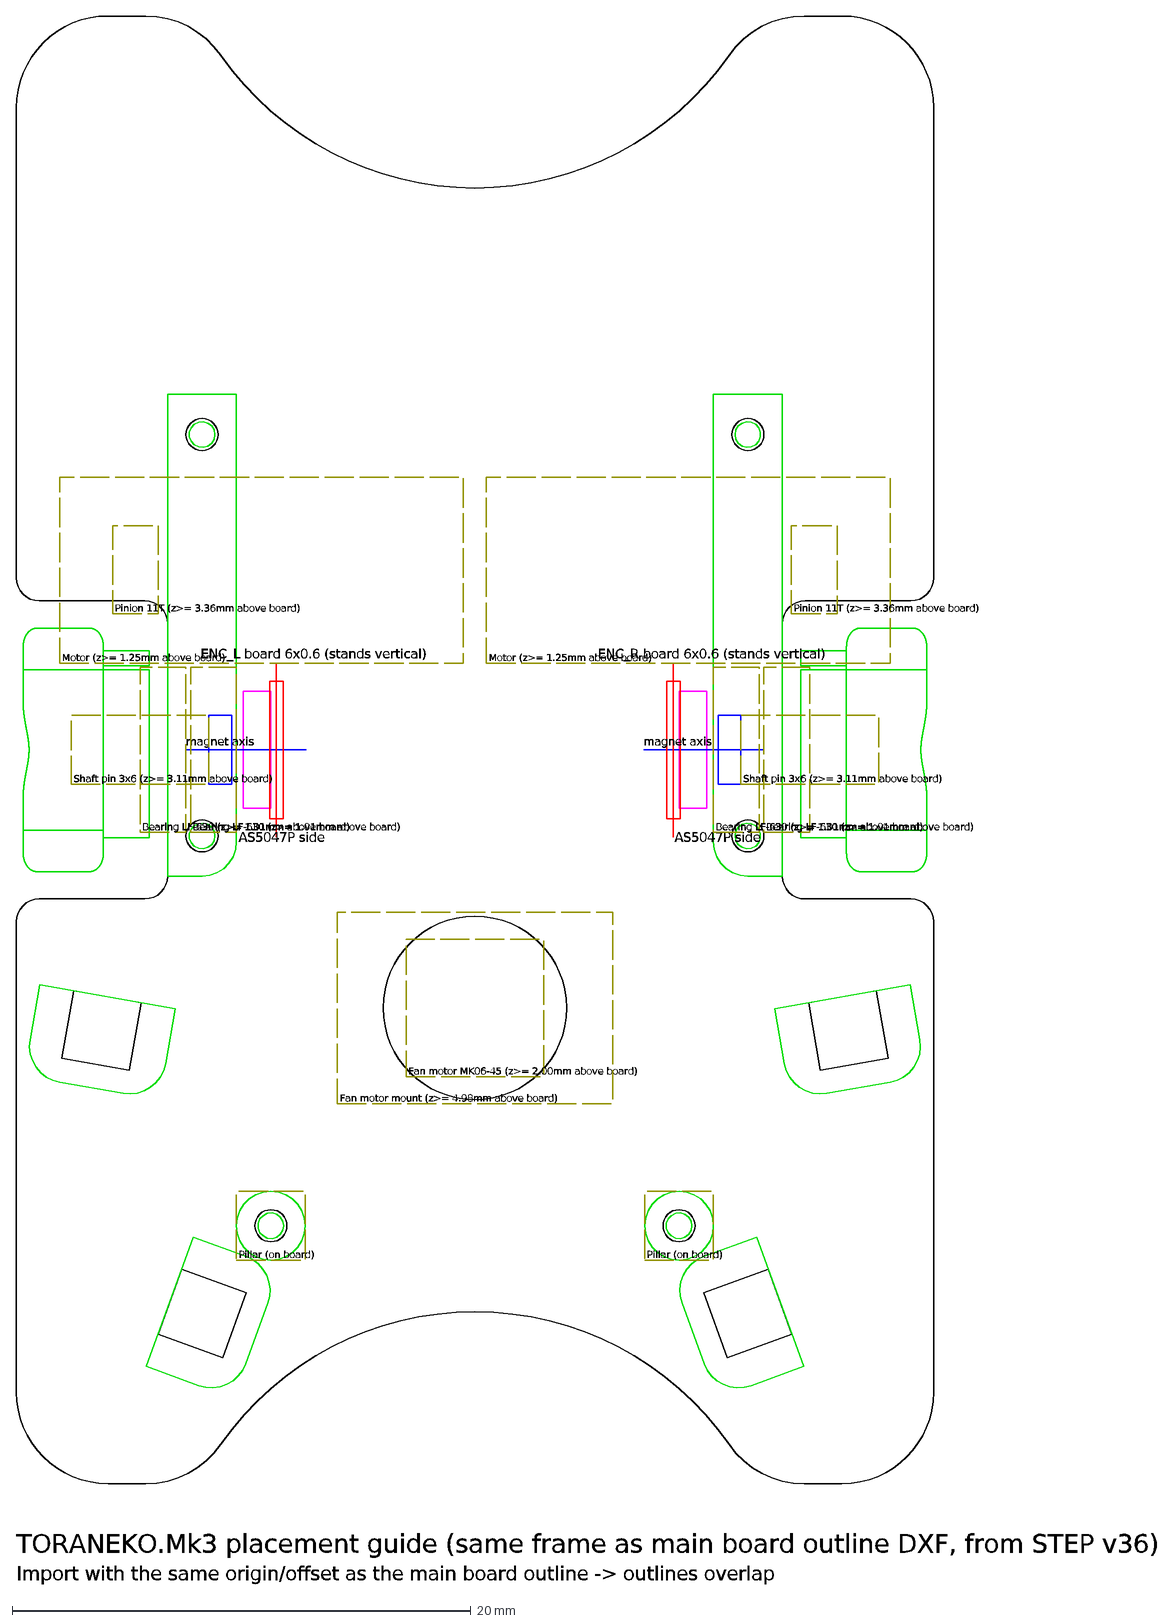
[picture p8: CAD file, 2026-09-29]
hardware/kicad/TORANEKO.Mk3/配置ガイド_メイン基板.dxf
ENC_R board 6x0.6 (stands vertical)
AS5047P side
magnet axis
ENC_L board 6x0.6 (stands vertical)
Motor (z>= 1.25mm above board)
Pinion 11T (z>= 3.36mm above board)
Bearing LF-630 (z>= 1.01mm above board)
Shaft pin 3x6 (z>= 3.11mm above board)
Fan motor MK06-45 (z>= 2.00mm above board)
Fan motor mount (z>= 4.98mm above board)
Pillar (on board)
TORANEKO.Mk3 placement guide (same frame as main board outline DXF, from STEP v36)
Import with the same origin/offset as the main board outline -> outlines overlap

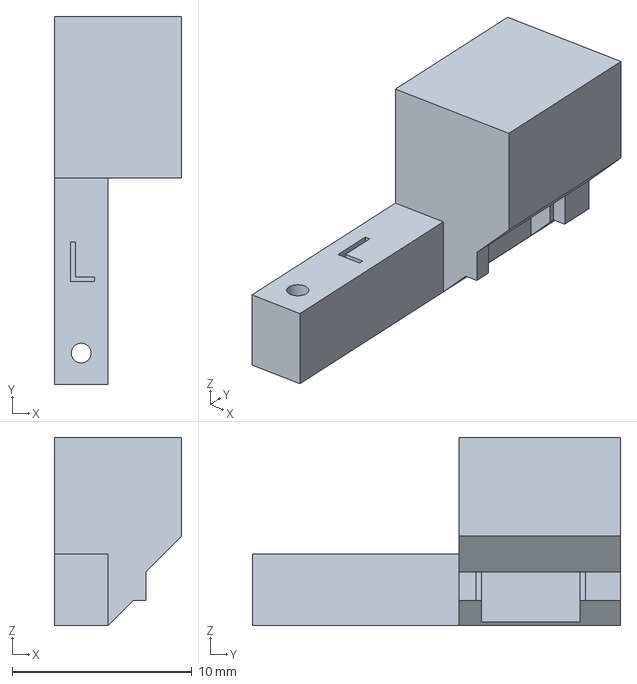
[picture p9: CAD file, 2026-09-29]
mechanical/jigs/encoder_solder_jig/encoder_jig_L.step
7.10 x 20.5 x 10.5 mm

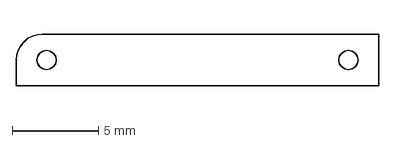
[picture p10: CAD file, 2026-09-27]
hardware/kicad/TORANEKO.Mk3/モータマウント.dxf
21.0 x 3.00 mm

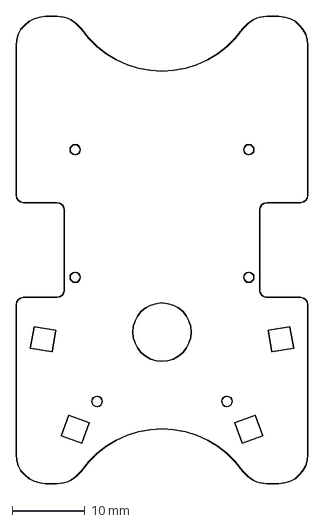
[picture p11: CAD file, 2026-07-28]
hardware/kicad/TORANEKO.Mk3/メイン基板外形.dxf
40.0 x 64.0 mm

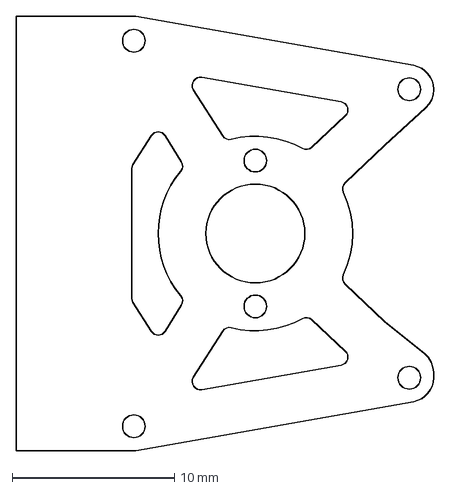
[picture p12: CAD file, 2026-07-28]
hardware/kicad/TORANEKO.Mk3/上部固定基板外形.dxf
25.8 x 26.8 mm

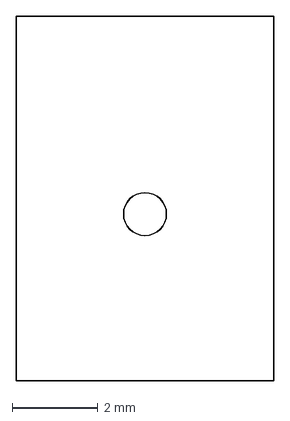
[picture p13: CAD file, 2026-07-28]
hardware/kicad/TORANEKO.Mk3/エンコーダ外形.dxf
6.00 x 8.50 mm

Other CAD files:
hardware/kicad/TORANEKO.Mk3/LIB_NCR321PASX/NCR321PASX/Allegro/ncr321pasx.psm
hardware/kicad/TORANEKO.Mk3/LIB_NCR321PASX/NCR321PASX/DEHDL/ncr321pasx/chips/chips.prt
mechanical/jigs/encoder_solder_jig/encoder_jig_L.stl
mechanical/jigs/encoder_solder_jig/encoder_jig_R.stl

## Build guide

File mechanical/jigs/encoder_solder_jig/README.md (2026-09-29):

# エンコーダ基板はんだ付け治具

エンコーダ基板（6 × 8.5 × 0.6mm）をメイン基板に垂直に立ててはんだ付けするための 3D プリント治具。
モータマウントの代わりに、マウントと同じ M1.4 穴 2 個（左 x=98、右 x=121.8、y=62.3 / 79.8）に基板裏からネジ止めする。
磁石と同じ基準で位置が決まるので、AS5047P と磁石の位置関係がずれにくい。

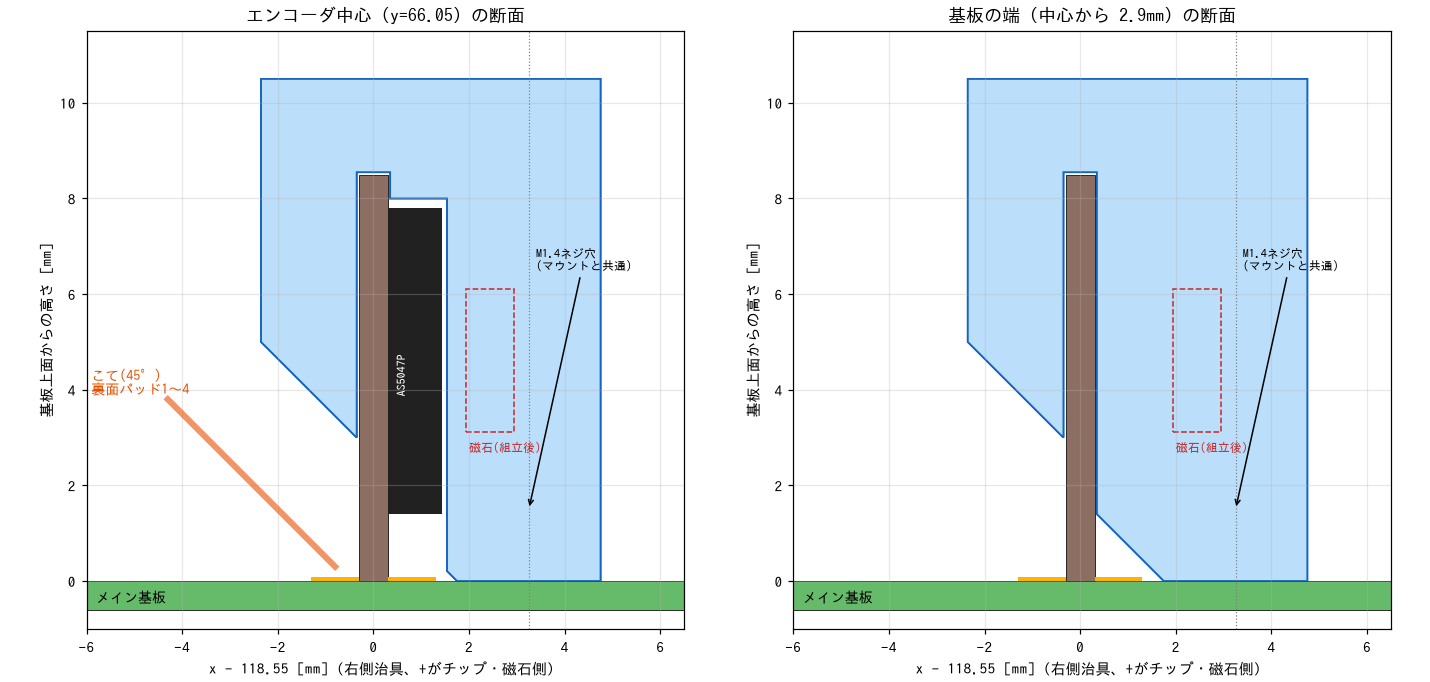
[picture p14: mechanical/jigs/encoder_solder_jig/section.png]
断面


| ファイル | 内容 |
|---|---|
| `encoder_solder_jig.py` | 生成スクリプト（CadQuery）。寸法はファイル先頭のパラメータで変える |
| `encoder_jig_L.stl/.step` | 左（U4、x=101.25）用 |
| `encoder_jig_R.stl/.step` | 右（U6、x=118.55）用。L と鏡像 |
| `slot_width_test.stl` | スロット幅テスト片（0.60〜0.85mm） |

## 保持の仕組み

- 上からスロット（既定 0.7mm 幅）で挟み、天井で上端を押さえる
- 裏面は高さ 3〜8.5mm の壁、チップ面は AS5047P の逃げの上端の帯と基板両端の帯で受ける
- 計算上、チップ・磁石方向 ±0.05mm、倒れ 1° 未満

## 使い方

1. `slot_width_test.stl` を刷り、エンコーダ基板が軽く入ってガタのない幅を選ぶ。`SLOT_C =（選んだ幅 − 0.6）/ 2` にして `python3 encoder_solder_jig.py` で作り直す
2. 前側の端面（エンコーダに近いネジ穴側）を下にした横置きで印刷（サポート不要）
3. 治具を M1.4 × 4 で基板裏からネジ止めし、エンコーダ基板をスロットに差し込む
4. 裏面パッド 1〜4 を、こて 45° 前後ではんだ付け
5. 治具を外し、チップ面の VCC/GND パッド（5, 6）をはんだ付け

モータマウント・モータ・上部固定基板を付ける前に使う（治具の高さ 10.5mm）。

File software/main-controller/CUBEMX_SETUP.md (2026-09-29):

# CubeMX 設定（ステップ0）

STM32CubeIDE で `TORANEKO.Mk3` プロジェクトを新規作成するときの `.ioc` 設定値です。
ピン割り当ては [PIN_REQUIREMENTS.md](PIN_REQUIREMENTS.md) の確定表に従います。

「KOGUMA」列は参考用に KOGUMA.MkIIl（F446, 180MHz）の設定を載せています。

## 1. プロジェクト作成

| 項目 | 設定 |
|---|---|
| MCU | STM32F411CEUx（UFQFPN48） |
| Project Name | `TORANEKO.Mk3` |
| 作成場所 | `software/main-controller/TORANEKO.Mk3/` |
| Targeted Project Type | STM32Cube |
| Project Manager → Code Generator → Generate peripheral initialization as a pair of '.c/.h' files per peripheral | **ON**（`Core/Src/tim.c` などに分かれる。README のファイル構成どおり） |
| Project Manager → Code Generator → Keep User Code when re-generating | ON |
| Project Manager → Code Generator → Delete previously generated files when not re-generated | ON |

## 2. System Core

### SYS

| 項目 | 設定 | 備考 |
|---|---|---|
| Debug | **Serial Wire** | これを設定しないと PB3/PB4/PA15（JTAG 兼用ピン）が IMU の SPI・CS に使えない |
| Timebase Source | SysTick | |

### RCC

| 項目 | 設定 |
|---|---|
| High Speed Clock (HSE) | **Crystal/Ceramic Resonator**（CSTNE10M0G52Z000R0、負荷容量内蔵） |
| Low Speed Clock (LSE) | Disable |

### GPIO（出力・入力）

| ピン | モード | 初期出力 | プル | 速度 | User Label |
|---|---|---|---|---|---|
| PA11 | GPIO_Output | Low | なし | Low | `LED1` |
| PA10 | GPIO_Output | Low | なし | Low | `LED2` |
| PB12 | GPIO_Output | Low | なし | Low | `LED3` |
| PB10 | GPIO_Output | Low | なし | Low | `LED4` |
| PB2 | GPIO_Output | Low | なし | Low | `LED5` |
| PB1 | GPIO_Output | Low | なし | Low | `LED6` |
| PA0 | GPIO_Output | Low | なし | Low | `LED7` |
| PB0 | GPIO_Output | Low | なし | Low | `WALL_LED_A` |
| PA7 | GPIO_Output | Low | なし | Low | `WALL_LED_B` |
| PA15 | GPIO_Output | **High** | なし | High | `IMU_CS` |
| PA8 | GPIO_Output | **High** | なし | High | `ENC_L_CS` |
| PC15 | GPIO_Output | **High** | なし | **Low**（PC13〜15 は 2MHz 以下の制約あり） | `ENC_R_CS` |
| PA12 | GPIO_Input | - | なし（外付け 10k プルダウンあり） | - | `SW_USER` |
| PC13, PC14 | 未設定（Analog のまま） | - | - | - | - |

- CS ピンは初期値 High（非選択）にする。Low で起動すると、電源投入直後に IMU・エンコーダが選択状態になる
- 壁センサ LED（`WALL_LED_A` / `WALL_LED_B`）は初期値 Low（消灯）

## 3. クロック構成（Clock Configuration）

| 項目 | 値 | KOGUMA |
|---|---|---|
| Input frequency (HSE) | **10 MHz** | 10 MHz |
| PLL Source | HSE | HSE |
| PLLM | **/5**（VCO 入力 2MHz） | - |
| PLLN | **×200**（VCO 400MHz） | - |
| PLLP | **/4** | - |
| PLLQ | /9 など（USB 不使用。48MHz 以下になれば何でもよい） | - |
| System Clock Mux | PLLCLK | PLLCLK |
| **SYSCLK / HCLK** | **100 MHz** | 180 MHz |
| AHB Prescaler | /1 | /1 |
| APB1 Prescaler | **/2 → PCLK1 = 50 MHz**（APB1 タイマー = 100 MHz） | 45 MHz（タイマー 90 MHz） |
| APB2 Prescaler | **/1 → PCLK2 = 100 MHz**（APB2 タイマー = 100 MHz） | 90 MHz（タイマー 180 MHz） |
| Power Regulator Voltage Scale | Scale 1（100MHz 動作に必要） | |
| Flash Latency | 3 WS（CubeMX が自動設定） | |

**全タイマーのクロックが 100MHz にそろう**ので、分周値の計算が簡単になります。

## 4. タイマー

| 用途 | タイマー | モード | PSC | ARR（Period） | 周波数 | 備考 |
|---|---|---|---|---|---|---|
| モータ PWM | **TIM4** CH1〜CH4 | PWM Generation CH1〜CH4 | 10-1 | 200-1 | **50 kHz** | 分解能 200 は KOGUMA と同じなので、`motor.c` の `200 - Motor_Voltage` の考え方がそのまま使える。MP6551 の入力 PWM 周波数の上限はステップ5で確認 |
| 吸引ファン PWM | **TIM2** CH2 | PWM Generation CH2 | 20-1 | 100-1 | **50 kHz** | KOGUMA と同じ周波数・分解能 |
| 制御周期 | **TIM11** | Activated（内部クロック、ピン不使用） | 100-1 | **500-1** | **2 kHz** | NVIC: `TIM1_TRG_COM_TIM11_IRQn` を有効化。4kHz にする場合は ARR を 250-1 に |
| 壁センサの順番制御 | **TIM3** | Activated（内部クロック、ピン不使用）、**One Pulse Mode** | 100-1 | 35-1 | 1回 35µs | Trigger Event Selection（TRGO）= **Update Event**。LED 点灯と同時に起動し、35µs 後に ADC を起動する。割り込みは不要 |
| 処理時間計測・µs 待ち | **TIM5** | Activated（内部クロック） | 100-1 | 0xFFFFFFFF | 1 MHz でカウント | 32bit フリーランカウンタ |

KOGUMA の設定（参考）: TIM3 PSC 9-1 / ARR 200-1（50kHz）、TIM2 PSC 18-1 / ARR 100-1（50kHz）、TIM6 PSC 90-1 / ARR 1000-1（1kHz）。

## 5. ADC1

| 項目 | 設定 | KOGUMA |
|---|---|---|
| 入力 | IN2, IN3, IN4, IN5, IN6 | IN9〜IN13 |
| Clock Prescaler | **PCLK2 / 4 = 25 MHz**（上限 36MHz） | PCLK2 / 8 |
| Resolution | 12 bit | 12 bit |
| Scan Conversion Mode | Enable | Enable |
| Continuous Conversion Mode | Disable（1回ずつソフトで開始） | Enable |
| DMA Continuous Requests | Disable | Enable |
| External Trigger Conversion Source | **Timer 3 Trigger Out event**（立ち上がり） | Software |
| Number Of Conversion | 5 | 5 |
| DMA | ADC1 → **DMA2 Stream0**、Peripheral to Memory、Half Word、Normal | DMA2 Stream0 |

変換順（Rank）は KOGUMA と同じ並びにして、DMA バッファの添字を流用できるようにします。

| Rank | チャンネル | ピン | 信号 | バッファ | Sampling Time |
|---|---|---|---|---|---|
| 1 | IN2 | PA2 | BATT | `[0]` | 15 cycles |
| 2 | IN3 | PA3 | Wallsen-4 | `[1]` | 15 cycles |
| 3 | IN4 | PA4 | Wallsen-3 | `[2]` | 15 cycles |
| 4 | IN5 | PA5 | Wallsen-2 | `[3]` | 15 cycles |
| 5 | IN6 | PA6 | Wallsen-1 | `[4]` | 15 cycles |

- 5ch の変換時間は (15+12) × 5 / 25MHz ≒ 5.4µs
- 壁センサは「組A 点灯と同時に TIM3 を起動 → 35µs 後に TIM3 が ADC を起動 → 5ch スキャン → DMA 完了割り込みで組A 消灯・組B 点灯して TIM3 を再起動 → …」を2段連鎖させる（受光素子 LTR-209 の立ち上がり 10µs・立ち下がり 15µs のため 35µs 待つ）。消灯時の値（外乱光）も連鎖の中で1回測る。連鎖全体で約 100µs。詳細はステップ6で詰める
- バッテリ電圧の換算: `V = AD × 3.3 / 4095 × (100 + 47) / 47`（KOGUMA は `× (47 + 10) / 10`）

## 6. SPI

| 項目 | SPI1（IMU: LSM6DSRX） | SPI2（エンコーダ: AS5047P ×2） |
|---|---|---|
| ピン | PB3 SCK / PB4 MISO / PB5 MOSI（**CubeMX の初期ピン PA5〜7 から付け替える**） | PB13 SCK / PB14 MISO / PB15 MOSI |
| Mode | Full-Duplex Master | Full-Duplex Master |
| Hardware NSS | Disable（CS は GPIO で制御） | Disable |
| Data Size | 8 bit | 8 bit（KOGUMA と同じく 2 バイトで 16bit フレームを送る） |
| First Bit | MSB | MSB |
| CPOL / CPHA | High / 2 Edge（モード3、KOGUMA と同じ） | High / 2 Edge（KOGUMA で動作実績あり。データシート上のモードはステップ3で確認） |
| Prescaler | **/16 → 6.25 MHz**（APB2 100MHz。LSM6DSRX 上限 10MHz） | **/8 → 6.25 MHz**（APB1 50MHz。AS5047P 上限 10MHz） |
| KOGUMA | /8（11.25MHz） | SPI3 /2（22.5MHz） |

KOGUMA は両方ともデータシートの上限を超えるクロックで動かしていたので、ToraNeko では上限内に収めます。速度が足りなければステップ3・4で見直します。

## 7. USART1（ログ出力）

| 項目 | 設定 | KOGUMA |
|---|---|---|
| Mode | Asynchronous | USART2 Single Wire (Half-Duplex) |
| Baud Rate | 115200 bps（まずはこれで動作確認。ログ吸い出し用に後で 1〜2Mbps へ上げる） | 115200 bps |
| Word Length / Parity / Stop | 8 bit / None / 1 | 同じ |
| Data Direction | **Transmit Only** | - |
| TX ピン | PA9 | PA2 |
| DMA | USART1_TX → DMA2 Stream7（Memory to Peripheral、Byte、Normal） | なし |

- Asynchronous にすると CubeMX が **PA10 を USART1_RX に自動で割り当てる**。PA10 は LED2 なので、PA10 をクリックして GPIO_Output に設定し直す
- KOGUMA の半二重モードは TX ピンがオープンドレインになるため、STLINK-V3MODS 側にプルアップがないと信号が出ない可能性がある。ToraNeko では通常の非同期モード（TX のみ）にする

## 8. NVIC（割り込み優先度の案）

| 割り込み | 優先度 | 用途 |
|---|---|---|
| DMA2 Stream0（ADC1） | 1 | 壁センサの連鎖（次の LED へ進める）・バッテリの変換完了 |
| TIM1_TRG_COM_TIM11 | 2 | 2kHz 制御周期 |
| DMA2 Stream7（USART1_TX） | 5 | ログ送信完了 |
| SysTick | CubeMX の既定値 | `HAL_Delay` 用。割り込み処理の中では `HAL_Delay` を使わない |

壁センサの連鎖を制御周期より高い優先度にし、制御処理が長引いてもセンサ測定が遅れないようにします。

## 9. 生成後にやること

1. `Core/Src/main.c` の USER CODE 欄に `app_init();` と `app_loop();` の呼び出しだけを書く（README のファイル構成どおり）
2. `App/` フォルダを作り、プロジェクトのインクルードパス・ソースフォルダに追加する
3. ビルドが通ること、STLINK-V3MODS で書き込めることを確認する
4. `software/main-controller/TORANEKO.Mk3/` をコミットする（`Debug/` などのビルド成果物は `.gitignore` で除外）

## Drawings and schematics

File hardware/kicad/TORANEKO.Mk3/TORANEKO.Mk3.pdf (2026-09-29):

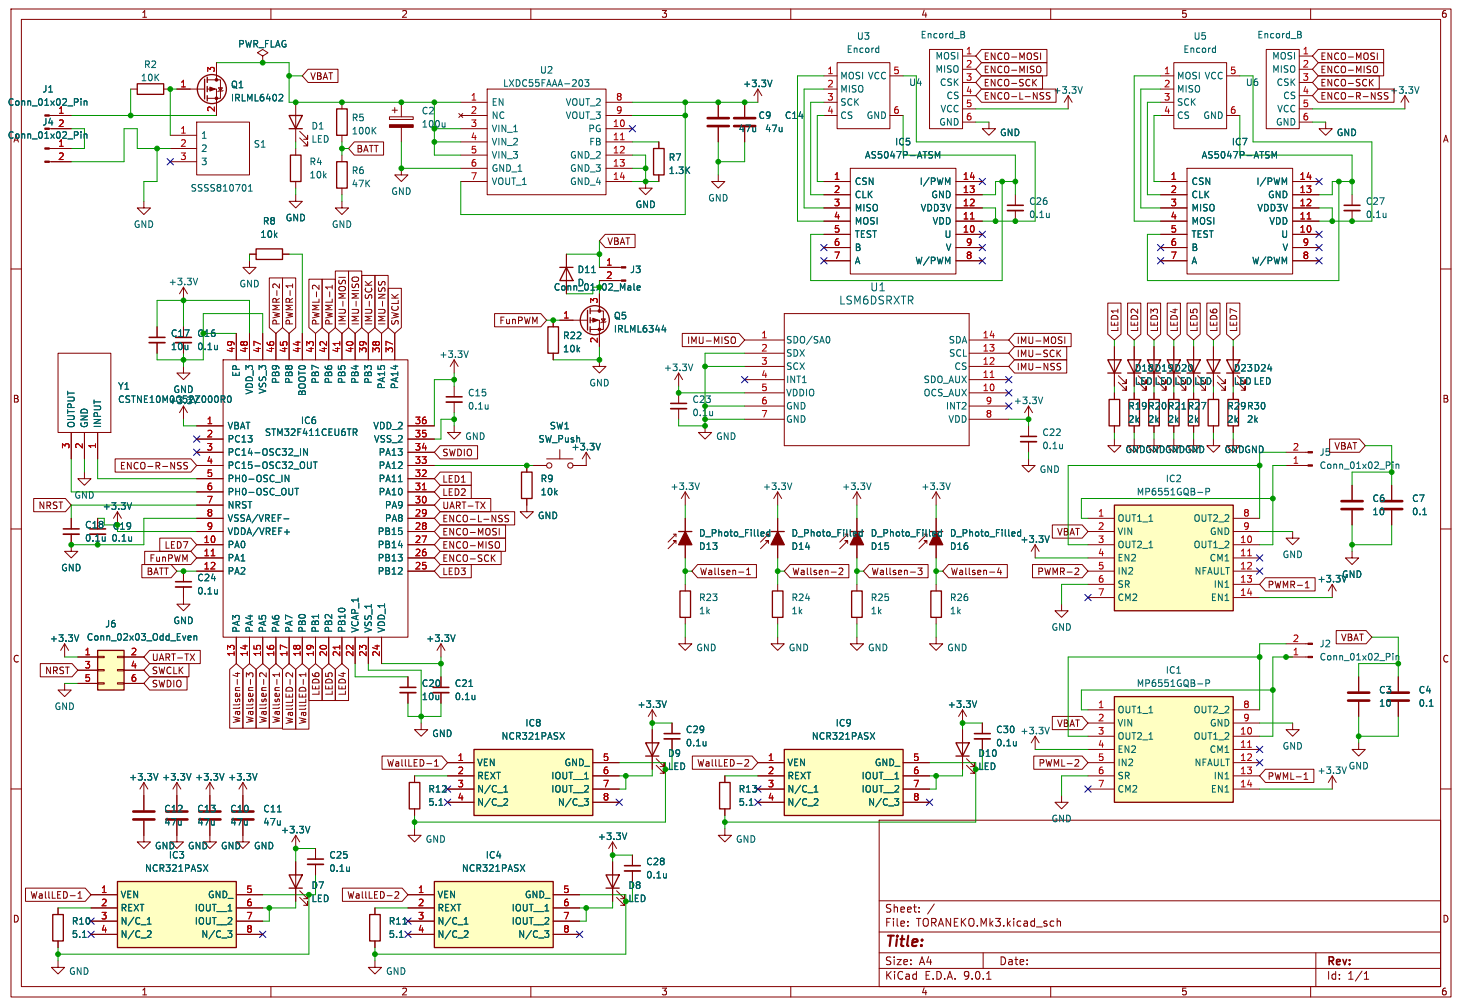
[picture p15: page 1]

ENCO-MOSI ENCO-L-NSS
ENCO-MISO
+3.3V GND

ENCO-MOSI ENCO-R-NSS
ENCO-SCK

Id: 1/1 Title: File: TORANEKO.Mk3.kicad_sch Sheet: /

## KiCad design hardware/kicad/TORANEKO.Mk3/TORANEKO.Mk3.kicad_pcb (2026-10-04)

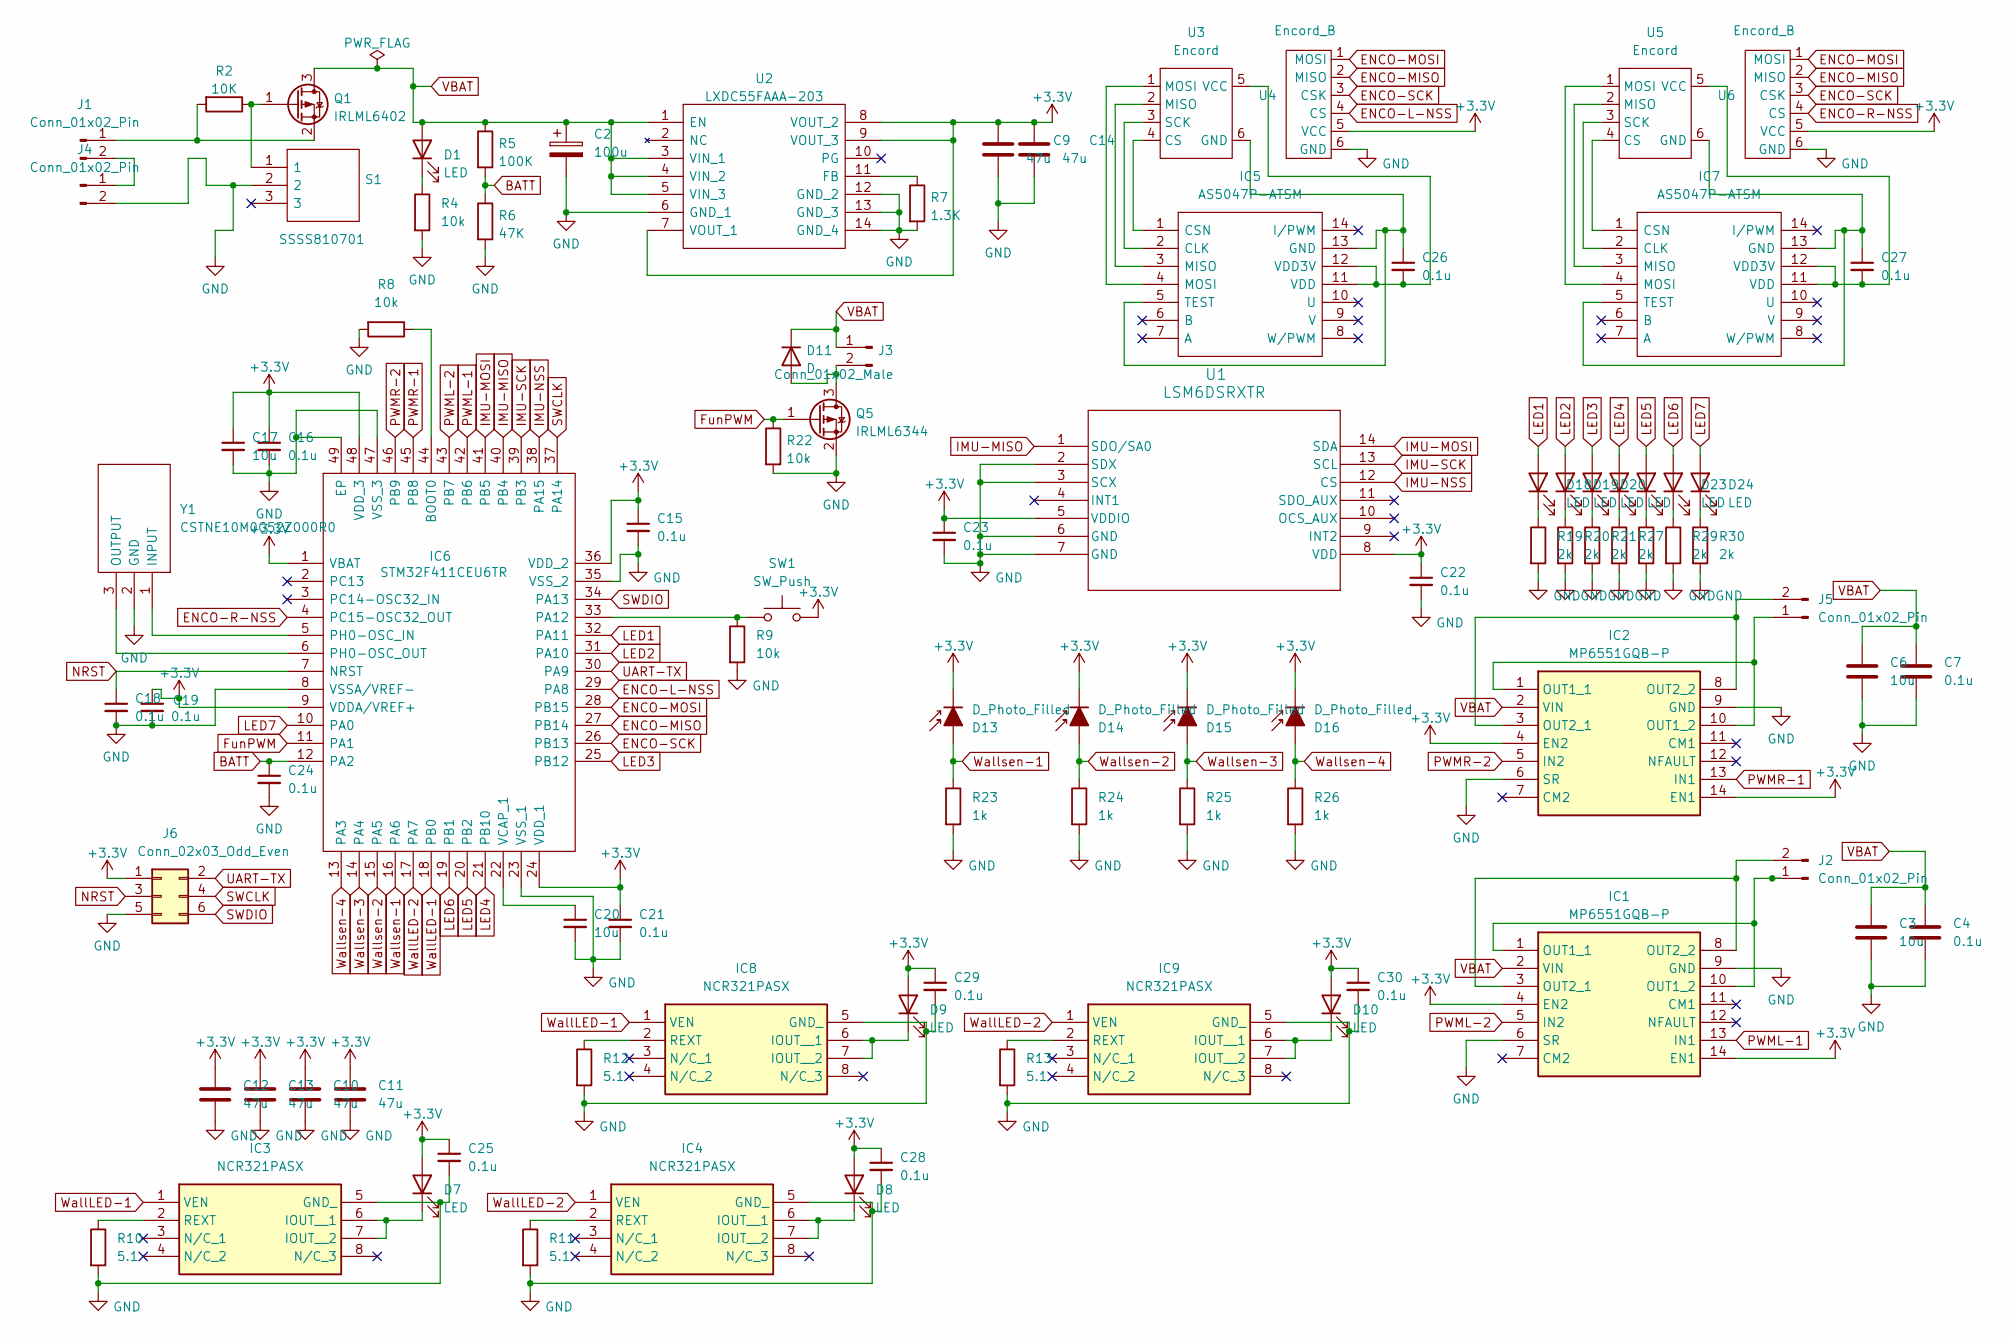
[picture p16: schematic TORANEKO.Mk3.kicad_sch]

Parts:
C2: 100u; CP_Elec_6.3x5.4
C3, C6, C17, C20: 10u; C_0402_1005Metric
C4, C7, C15, C16, C18, C19, C21, C22, C23, C24, C25, C26, C27, C28, C29, C30: 0.1u; C_0402_1005Metric
C9, C10, C11, C12, C13, C14: 47u; C_0603_1608Metric
D1, D18, D19, D20, D21, D22, D23, D24: LED; LED_0402_1005Metric
D7, D8, D9, D10: LED; LED_D3.0mm
D11: D; D_SOD-123F
D13, D14, D15, D16: D_Photo_Filled; LED_D3.0mm
IC1, IC2: MP6551GQB-P; MP6551GQBP; Manufacturer_Part_Number MP6551GQB-P
IC3, IC4, IC8, IC9: NCR321PASX; Manufacturer_Part_Number NCR321PASX
IC5, IC7: AS5047P-ATSM; SOP65P640X120-14N; Manufacturer_Part_Number AS5047P-ATSM
IC6: STM32F411CEU6TR; QFN50P700X700X60-49N-D; Manufacturer_Part_Number STM32F411CEU6TR
J1, J4: Conn_01x02_Pin; JST_ZH_B2B-ZR_1x02_P1.50mm_Vertical
J2, J5: Conn_01x02_Pin; C_0805_2012Metric
J3: Conn_01x02_Male; C_0805_2012Metric
J6: Conn_02x03_Odd_Even; PinHeader_2x03_P1.27mm_Vertical
Q1: IRLML6402; SOT-23
Q5: IRLML6344; SOT-23
R2: 10K; R_0402_1005Metric
R4, R8, R9, R22: 10k; R_0402_1005Metric
R5: 100K; R_0402_1005Metric
R6: 47K; R_0402_1005Metric
R7: 1.3K; R_0402_1005Metric
R10, R11, R12, R13: 5.1; R_0402_1005Metric
R19, R20, R21, R27, R28, R29, R30: 2k; R_0402_1005Metric
R23, R24, R25, R26: 1k; R_0402_1005Metric
S1: SSSS810701; Manufacturer_Part_Number SSSS810701
SW1: SW_Push; SW_Push_SPST_NO_Alps_SKRK
U1: LSM6DSRXTR; LGA-14L_STM
U2: LXDC55FAAA-203; LXDC55FAAA203; Manufacturer_Part_Number LXDC55FAAA-203
U3, U5: Encord; TN_ENC_Edge
U4, U6: Encord_B; TN_ENC_Base
Y1: CSTNE10M0G52Z000R0; Manufacturer_Part_Number CSTNE10M0G52Z000R0

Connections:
+3.3V: C9.1, C10.1, C11.1, C12.1, C13.1, C14.1, C15.1, C16.1, C17.1, C19.1, C21.1, C22.1, C23.1, C25.1, C28.1, C29.1, C30.1, D7.2 (A), D8.2 (A), D9.2 (A), D10.2 (A), D13.1 (K), D14.1 (K), D15.1 (K), D16.1 (K), IC1.4 (EN2), IC1.14 (EN1), IC2.4 (EN2), IC2.14 (EN1), IC6.1 (VBAT), IC6.9 (VDDA/VREF+), IC6.24 (VDD_1), IC6.36 (VDD_2), IC6.48 (VDD_3), J6.1, SW1.2, U1.5 (VDDIO), U1.8 (VDD), U2.7 (VOUT_1), U2.8 (VOUT_2), U2.9 (VOUT_3), U4.5 (VCC), U6.5 (VCC)
BATT: C24.1, IC6.12 (PA2), R5.2, R6.1
ENCO-L-NSS: IC6.29 (PA8), U4.4 (CS)
ENCO-MISO: IC6.27 (PB14), U4.2 (MISO), U6.2 (MISO)
ENCO-MOSI: IC6.28 (PB15), U4.1 (MOSI), U6.1 (MOSI)
ENCO-R-NSS: IC6.4 (PC15-OSC32_OUT), U6.4 (CS)
ENCO-SCK: IC6.26 (PB13), U4.3 (CSK), U6.3 (CSK)
FunPWM: IC6.11 (PA1), Q5.1 (G), R22.1
GND: C2.2, C3.2, C4.2, C6.2, C7.2, C9.2, C10.2, C11.2, C12.2, C13.2, C14.2, C15.2, C16.2, C17.2, C18.2, C19.2, C20.2, C21.2, C22.2, C23.2, C24.2, C25.2, C28.2, C29.2, C30.2, IC1.6 (SR), IC1.9 (GND), IC2.6 (SR), IC2.9 (GND), IC3.5 (GND_), IC4.5 (GND_), IC6.8 (VSSA/VREF-), IC6.23 (VSS_1), IC6.35 (VSS_2), IC6.47 (VSS_3), IC6.49 (EP), IC8.5 (GND_), IC9.5 (GND_), J4.2, J6.5, Q5.2 (S), R4.2, R6.2, R7.2, R8.2, R9.2, R10.2, R11.2, R12.2, R13.2, R19.2, R20.2, R21.2, R22.2, R23.2, R24.2, R25.2, R26.2, R27.2, R28.2, R29.2, R30.2, S1.2, U1.2 (SDX), U1.3 (SCX), U1.6 (GND), U1.7 (GND), U2.6 (GND_1), U2.12 (GND_2), U2.13 (GND_3), U2.14 (GND_4), U4.6 (GND), U6.6 (GND), Y1.2 (GND)
IMU-MISO: IC6.40 (PB4), U1.1 (SDO/SA0)
IMU-MOSI: IC6.41 (PB5), U1.14 (SDA)
IMU-NSS: IC6.38 (PA15), U1.12 (CS)
IMU-SCK: IC6.39 (PB3), U1.13 (SCL)
LED1: D18.2 (A), IC6.32 (PA11)
LED2: D19.2 (A), IC6.31 (PA10)
LED3: D20.2 (A), IC6.25 (PB12)
LED4: D21.2 (A), IC6.21 (PB10)
LED5: D22.2 (A), IC6.20 (PB2)
LED6: D23.2 (A), IC6.19 (PB1)
LED7: D24.2 (A), IC6.10 (PA0)
NRST: C18.1, IC6.7 (NRST), J6.3
unnamed: D1.1 (K), R4.1
unnamed: D7.1 (K), IC3.6 (IOUT__1), IC3.7 (IOUT__2)
unnamed: D8.1 (K), IC4.6 (IOUT__1), IC4.7 (IOUT__2)
unnamed: D9.1 (K), IC8.6 (IOUT__1), IC8.7 (IOUT__2)
unnamed: D10.1 (K), IC9.6 (IOUT__1), IC9.7 (IOUT__2)
unnamed: D11.2 (A), J3.2, Q5.3 (D)
unnamed: D18.1 (K), R19.1
unnamed: D19.1 (K), R20.1
unnamed: D20.1 (K), R21.1
unnamed: D21.1 (K), R27.1
unnamed: D22.1 (K), R28.1
unnamed: D23.1 (K), R29.1
unnamed: D24.1 (K), R30.1
unnamed: IC1.1 (OUT1_1), IC1.10 (OUT1_2), J2.1
unnamed: IC1.3 (OUT2_1), IC1.8 (OUT2_2), J2.2
unnamed: IC2.1 (OUT1_1), IC2.10 (OUT1_2), J5.1
unnamed: IC2.3 (OUT2_1), IC2.8 (OUT2_2), J5.2
unnamed: IC3.2 (REXT), R10.1
unnamed: IC4.2 (REXT), R11.1
unnamed: IC5.2 (CLK), U3.3 (SCK)
unnamed: IC5.1 (CSN), U3.4 (CS)
unnamed: C26.1, IC5.5 (TEST), IC5.13 (GND), U3.6 (GND)
unnamed: IC5.3 (MISO), U3.2 (MISO)
unnamed: IC5.4 (MOSI), U3.1 (MOSI)
unnamed: C26.2, IC5.11 (VDD), IC5.12 (VDD3V), U3.5 (VCC)
unnamed: IC6.44 (BOOT0), R8.1
unnamed: IC6.33 (PA12), R9.1, SW1.1
unnamed: IC6.5 (PH0-OSC_IN), Y1.1 (INPUT)
unnamed: IC6.6 (PH0-OSC_OUT), Y1.3 (OUTPUT)
unnamed: C20.1, IC6.22 (VCAP_1)
unnamed: IC7.2 (CLK), U5.3 (SCK)
unnamed: IC7.1 (CSN), U5.4 (CS)
unnamed: C27.1, IC7.5 (TEST), IC7.13 (GND), U5.6 (GND)
unnamed: IC7.3 (MISO), U5.2 (MISO)
unnamed: IC7.4 (MOSI), U5.1 (MOSI)
unnamed: C27.2, IC7.11 (VDD), IC7.12 (VDD3V), U5.5 (VCC)
unnamed: IC8.2 (REXT), R12.1
unnamed: IC9.2 (REXT), R13.1
unnamed: J1.1, Q1.2 (S), R2.2
unnamed: J1.2, J4.1
unnamed: Q1.1 (G), R2.1, S1.1
unnamed: R7.1, U2.11 (FB)
PWML-1: IC1.13 (IN1), IC6.42 (PB6)
PWML-2: IC1.5 (IN2), IC6.43 (PB7)
PWMR-1: IC2.13 (IN1), IC6.45 (PB8)
PWMR-2: IC2.5 (IN2), IC6.46 (PB9)
SWCLK: IC6.37 (PA14), J6.4
SWDIO: IC6.34 (PA13), J6.6
UART-TX: IC6.30 (PA9), J6.2
VBAT: C2.1, C3.1, C4.1, C6.1, C7.1, D1.2 (A), D11.1 (K), IC1.2 (VIN), IC2.2 (VIN), J3.1, Q1.3 (D), R5.1, U2.1 (EN), U2.3 (VIN_1), U2.4 (VIN_2), U2.5 (VIN_3)
WallLED-1: IC3.1 (VEN), IC6.18 (PB0), IC8.1 (VEN)
WallLED-2: IC4.1 (VEN), IC6.17 (PA7), IC9.1 (VEN)
Wallsen-1: D13.2 (A), IC6.16 (PA6), R23.1
Wallsen-2: D14.2 (A), IC6.15 (PA5), R24.1
Wallsen-3: D15.2 (A), IC6.14 (PA4), R25.1
Wallsen-4: D16.2 (A), IC6.13 (PA3), R26.1

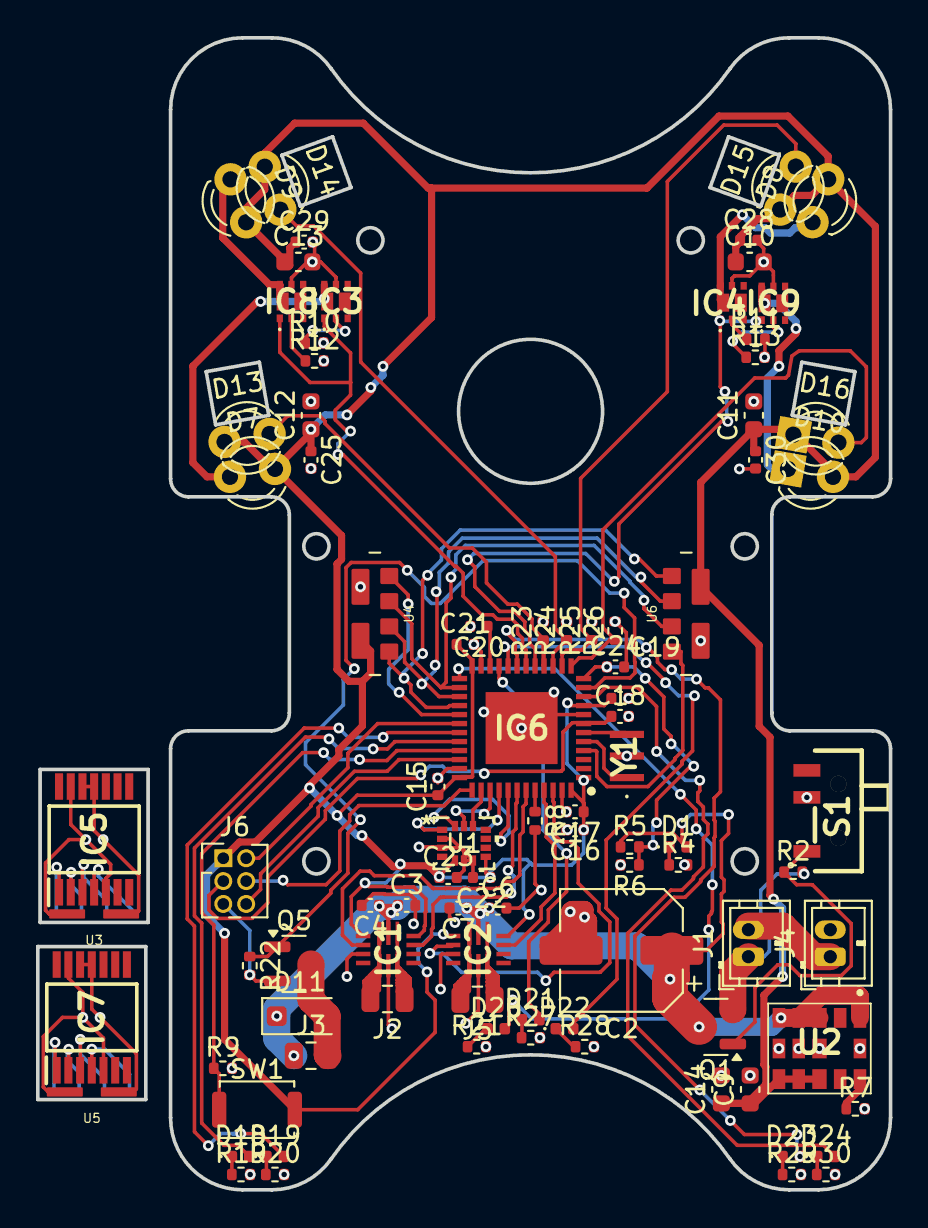
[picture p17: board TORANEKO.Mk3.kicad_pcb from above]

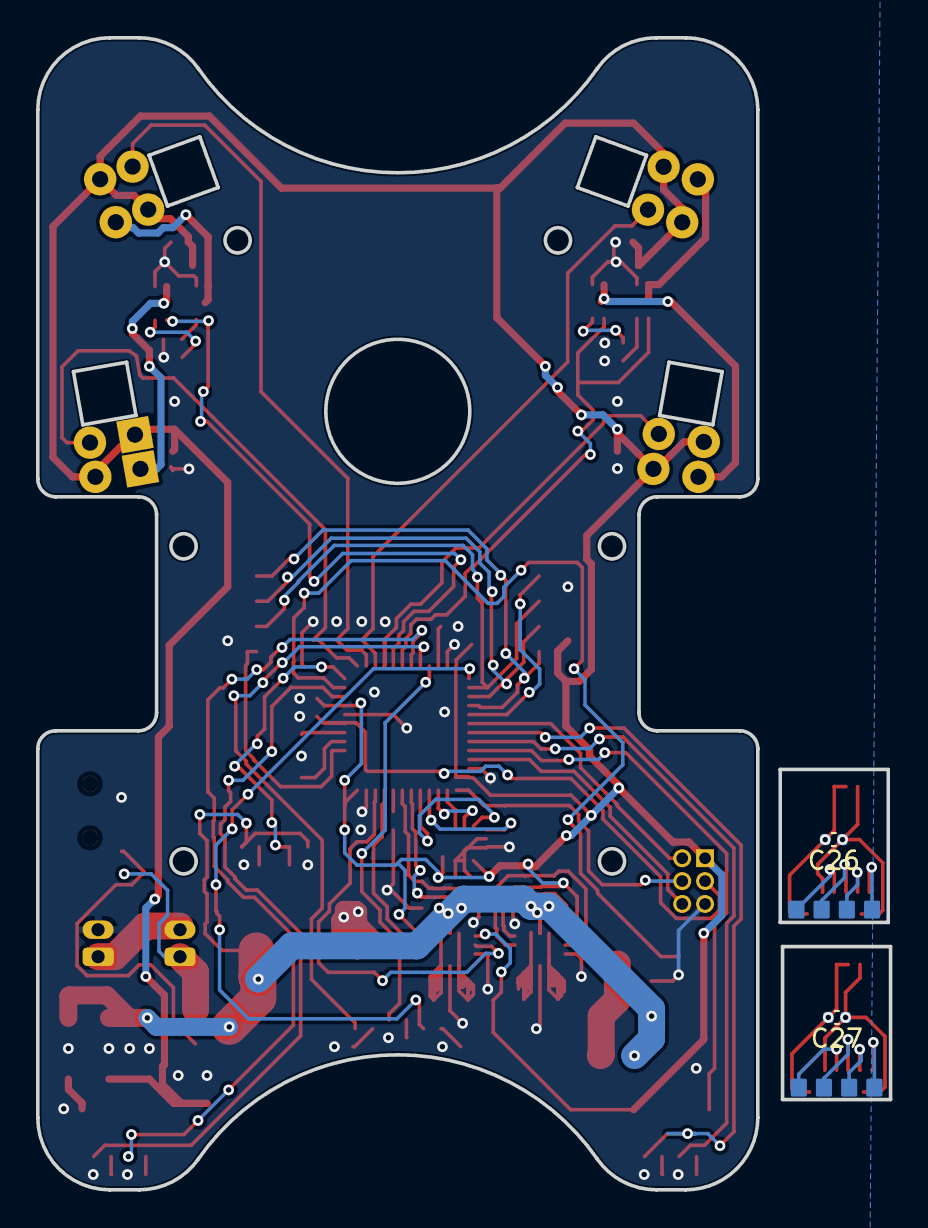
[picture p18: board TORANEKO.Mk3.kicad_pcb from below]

Board: 2 copper layers, 40.0 x 64.0 mm, 93 parts (2 on the bottom side), 77 nets.

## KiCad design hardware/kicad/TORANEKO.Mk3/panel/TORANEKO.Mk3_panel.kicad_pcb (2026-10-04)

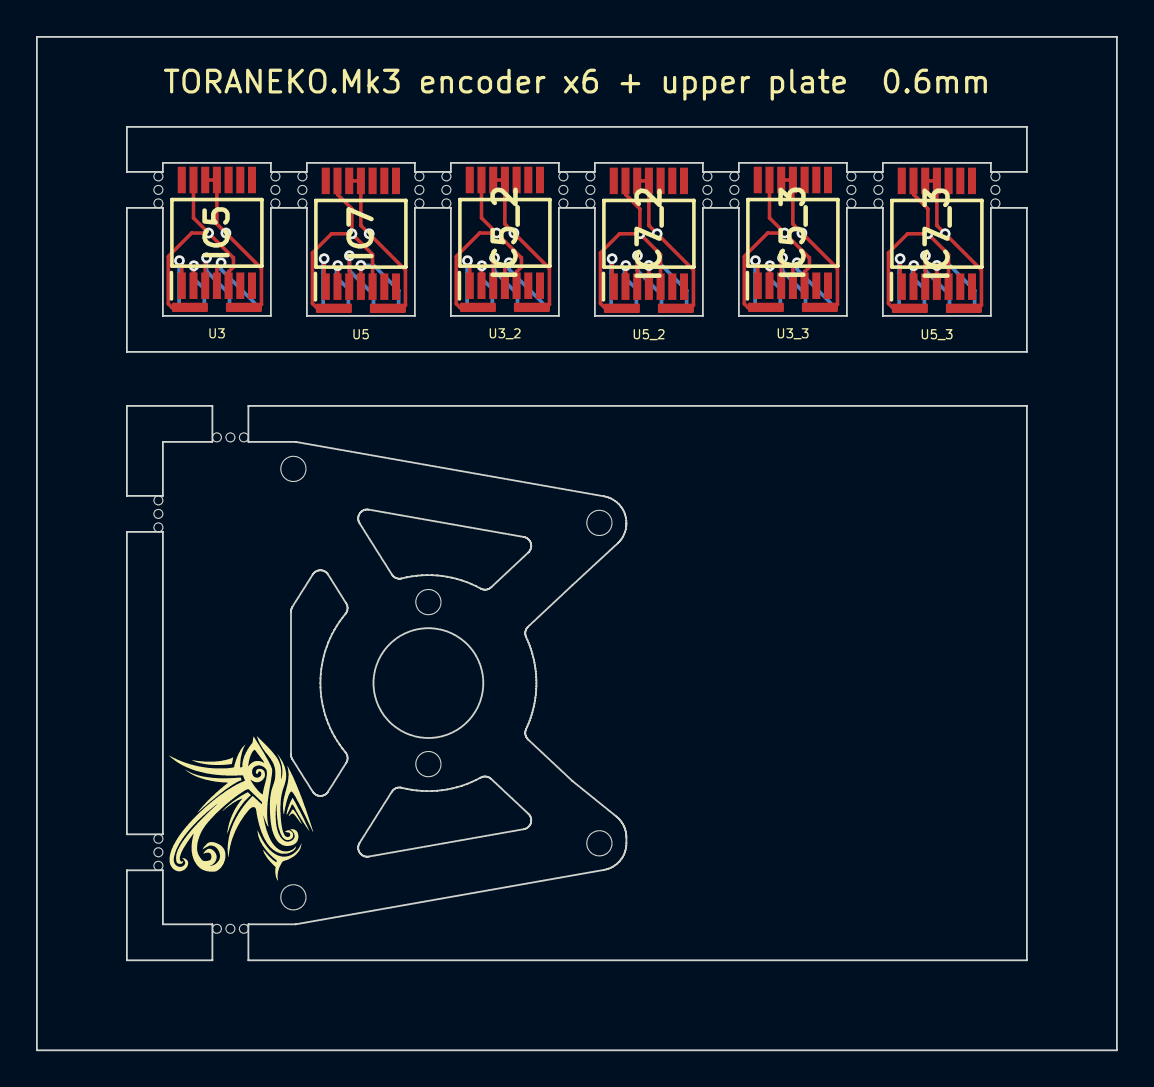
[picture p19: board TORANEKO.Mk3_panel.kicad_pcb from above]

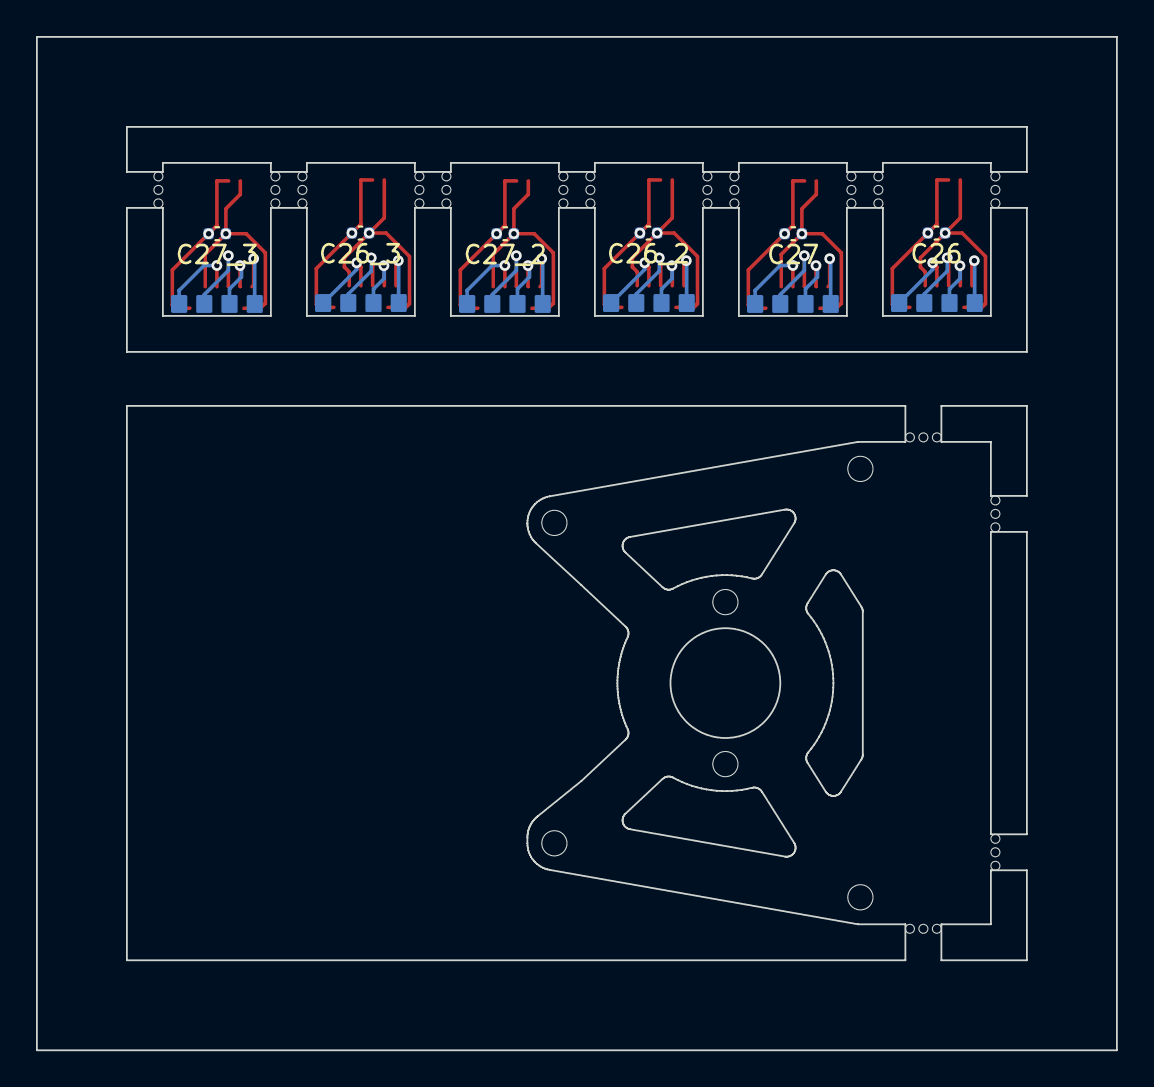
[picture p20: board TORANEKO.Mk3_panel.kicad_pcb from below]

Board: 2 copper layers, 60.0 x 56.3 mm, 21 parts (6 on the bottom side), 36 nets.

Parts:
C26, C26_2, C26_3, C27, C27_2, C27_3: 0.1u; C_0402_1005Metric
H101: UpperPlateHoles
IC5, IC5_2, IC5_3, IC7, IC7_2, IC7_3: AS5047P-ATSM; SOP65P640X120-14N
LOGO1: WhiteGlint; Logo
MB1: MouseBites
U3, U3_2, U3_3, U5, U5_2, U5_3: Encord; TN_ENC_Edge

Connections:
unnamed: IC5.2 (CLK), U3.3 (SCK)
unnamed: IC5_2.2 (CLK), U3_2.3 (SCK)
unnamed: IC5_3.2 (CLK), U3_3.3 (SCK)
unnamed: IC5.1 (CSN), U3.4 (CS)
unnamed: IC5_2.1 (CSN), U3_2.4 (CS)
unnamed: IC5_3.1 (CSN), U3_3.4 (CS)
unnamed: C26.1, IC5.5 (TEST), IC5.13 (GND), U3.6 (GND)
unnamed: C26_2.1, IC5_2.5 (TEST), IC5_2.13 (GND), U3_2.6 (GND)
unnamed: C26_3.1, IC5_3.5 (TEST), IC5_3.13 (GND), U3_3.6 (GND)
unnamed: IC5.3 (MISO), U3.2 (MISO)
unnamed: IC5_2.3 (MISO), U3_2.2 (MISO)
unnamed: IC5_3.3 (MISO), U3_3.2 (MISO)
unnamed: IC5.4 (MOSI), U3.1 (MOSI)
unnamed: IC5_2.4 (MOSI), U3_2.1 (MOSI)
unnamed: IC5_3.4 (MOSI), U3_3.1 (MOSI)
unnamed: C26.2, IC5.11 (VDD), IC5.12 (VDD3V), U3.5 (VCC)
unnamed: C26_2.2, IC5_2.11 (VDD), IC5_2.12 (VDD3V), U3_2.5 (VCC)
unnamed: C26_3.2, IC5_3.11 (VDD), IC5_3.12 (VDD3V), U3_3.5 (VCC)
unnamed: IC7.2 (CLK), U5.3 (SCK)
unnamed: IC7_2.2 (CLK), U5_2.3 (SCK)
unnamed: IC7_3.2 (CLK), U5_3.3 (SCK)
unnamed: IC7.1 (CSN), U5.4 (CS)
unnamed: IC7_2.1 (CSN), U5_2.4 (CS)
unnamed: IC7_3.1 (CSN), U5_3.4 (CS)
unnamed: C27.1, IC7.5 (TEST), IC7.13 (GND), U5.6 (GND)
unnamed: C27_2.1, IC7_2.5 (TEST), IC7_2.13 (GND), U5_2.6 (GND)
unnamed: C27_3.1, IC7_3.5 (TEST), IC7_3.13 (GND), U5_3.6 (GND)
unnamed: IC7.3 (MISO), U5.2 (MISO)
unnamed: IC7_2.3 (MISO), U5_2.2 (MISO)
unnamed: IC7_3.3 (MISO), U5_3.2 (MISO)
unnamed: IC7.4 (MOSI), U5.1 (MOSI)
unnamed: IC7_2.4 (MOSI), U5_2.1 (MOSI)
unnamed: IC7_3.4 (MOSI), U5_3.1 (MOSI)
unnamed: C27.2, IC7.11 (VDD), IC7.12 (VDD3V), U5.5 (VCC)
unnamed: C27_2.2, IC7_2.11 (VDD), IC7_2.12 (VDD3V), U5_2.5 (VCC)
unnamed: C27_3.2, IC7_3.11 (VDD), IC7_3.12 (VDD3V), U5_3.5 (VCC)

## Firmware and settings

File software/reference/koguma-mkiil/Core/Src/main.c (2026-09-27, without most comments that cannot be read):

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
/* Includes ------------------------------------------------------------------*/
#include "main.h"
#include "adc.h"
#include "dma.h"
#include "spi.h"
#include "tim.h"
#include "usart.h"
#include "gpio.h"

/* USER CODE BEGIN Includes */
#include "lsm6dsr.h"
#include "motor.h"
#include "PL_encoder.h"
#include "PL_timer.h"
#include "Motor.h"
#include "LOG.h"
#include "PL_sensor.h"
#include "UI.h"
#include "Wallsensor.h"
#include "Maze.h"
#include "Move.h"
#include "Failsafe.h"
#include "Define.h"
/* USER CODE END Includes */


void SystemClock_Config(void);
/**
 * @brief  The application entry point.
 * @retval int
 */
int main(void) {

	/* MCU Configuration--------------------------------------------------------*/

	/* Reset of all peripherals, Initializes the Flash interface and the Systick. */
	HAL_Init();

	/* Configure the system clock */
	SystemClock_Config();

	/* Initialize all configured peripherals */
	MX_GPIO_Init();
	MX_DMA_Init();
	MX_ADC1_Init();
	MX_SPI1_Init();
	MX_SPI3_Init();
	MX_TIM2_Init();
	MX_TIM3_Init();
	MX_TIM4_Init();
	MX_USART2_UART_Init();
	MX_TIM6_Init();
	/* USER CODE BEGIN 2 */

	//HAL_TIM_Base_Start_IT(&htim6);
	pl_timer_init();
	lsm6dsr_init();
	Maze_Initialization();
	if (g_V_batt < LIMITBATT) {
		while (1) {
			LED_Reset();
			HAL_Delay(500);
			LED_ALL_ON();
			HAL_Delay(500);
		}
	}

	LED_Setup_Robot();

//
	HAL_TIM_PWM_Start(&htim4, TIM_CHANNEL_4); //buzeer
//
//	HAL_TIM_PWM_Start(&htim2, TIM_CHANNEL_1);

	/* USER CODE END 2 */

	/* Infinite loop */
	/* USER CODE BEGIN WHILE */
	while (1) {
		/* USER CODE END WHILE */

		/* USER CODE BEGIN 3 */

		LED_program_number(Encorder_number_out());
		LED_program_mode(Encorder_mode_out());
		Maze_Unkown_ALL_ModeOFF();
		Motor_Setup_Voltage();
		if (Encorder_mode_out() == 0) {		//大会用
			if (Encorder_number_out() == 0) {		//
				/////////////////////////////
			} else if (Encorder_number_out() == 1) {		//エセ全面探索
				if (Sensor_Enter() == 1) {
					Buzzer_Enter();
					Sensor_Start();

					Motor_Setup();
					Motor_Stop();

					G_Gool_X = MAZE_GOOL_X;
					G_Gool_Y = MAZE_GOOL_Y;
					G_Robot_MAZE_X = 0;
					G_Robot_MAZE_Y = 0;
					G_Robot_Direction = 0;
					G_MAZE_Explored[G_Gool_X][G_Gool_Y] = 0;

					Motor_trapezoid_PID(0, 500, 500, 5000, 24 + 90);
					while (G_MAZE_Explored[G_Gool_X][G_Gool_Y] == 0) {
						if (Failsafe_Flag() == 1) {
							break;
						}
						Robot_Maze_Sula_Action();
						//Robot_Maze_Pass_Action();
						G_MAZE_Explored[G_Robot_MAZE_X][G_Robot_MAZE_Y] = 1;
					}
					Maze_Save();

					Maze_Unkown_ALL_ModeSet();

					G_Gool_X = 0;
					G_Gool_Y = 0;
					G_MAZE_Explored[G_Gool_X][G_Gool_Y] = 0;
					Maze_Step_Calculate();
					while (G_MAZE_Explored[G_Gool_X][G_Gool_Y] == 0) {
						if (Failsafe_Flag() == 1) {
							break;
						}
						Robot_Maze_Sula_Action();
						//Robot_Maze_Pass_Action();
						G_MAZE_Explored[G_Robot_MAZE_X][G_Robot_MAZE_Y] = 1;
					}
					Motor_Stop();
					if (Failsafe_Flag() == 0) {
						Maze_Save();
					} else {
						Failsafe_Flag_OFF();
					}
					Motor_Free();
					LED_Reset();
					Encorder_count_reset();

				}
			} else if (Encorder_number_out() == 2) {
				if (Sensor_Enter() == 1) {
					Buzzer_Enter();
					Sensor_Start();

					Motor_Setup();
					Motor_Stop();

					G_Gool_X = MAZE_GOOL_X;
					G_Gool_Y = MAZE_GOOL_Y;
					G_Robot_MAZE_X = 0;
					G_Robot_MAZE_Y = 0;
					G_Robot_Direction = 0;
					G_MAZE_Explored[G_Gool_X][G_Gool_Y] = 0;

					Motor_trapezoid_PID(0, 500, 500, 5000, 24 + 90);
					while (G_MAZE_Explored[G_Gool_X][G_Gool_Y] == 0) {
						if (Failsafe_Flag() == 1) {
							break;
						}
						Robot_Maze_Sula_Action();
						//Robot_Maze_Pass_Action();
						G_MAZE_Explored[G_Robot_MAZE_X][G_Robot_MAZE_Y] = 1;
					}
					Maze_Save();

					//Maze_Unkown_ALL_ModeSet();

					G_Gool_X = 0;
					G_Gool_Y = 0;
					G_MAZE_Explored[G_Gool_X][G_Gool_Y] = 0;
					Maze_Step_Calculate();
					while (G_MAZE_Explored[G_Gool_X][G_Gool_Y] == 0) {
						if (Failsafe_Flag() == 1) {
							break;
						}
						Robot_Maze_Sula_Action();
						//Robot_Maze_Pass_Action();
						G_MAZE_Explored[G_Robot_MAZE_X][G_Robot_MAZE_Y] = 1;
					}
					Motor_Stop();

					if (Failsafe_Flag() == 0) {
						Maze_Save();
					} else {
						Failsafe_Flag_OFF();
					}

					Motor_Setup();
					Motor_Stop();
					if (Failsafe_Flag() == 0) {
						Maze_Save();
					} else {
						Failsafe_Flag_OFF();
					}
					Motor_Free();
					LED_Reset();
					Encorder_count_reset();
				}
			} else if (Encorder_number_out() == 3) {		//吸引探索
				if (Sensor_Enter() == 1) {
					Buzzer_Enter();
					Sensor_Start();

					Motor_Setup();
					Motor_Stop();

					Suction_Start(35);

					G_Gool_X = MAZE_GOOL_X;
					G_Gool_Y = MAZE_GOOL_Y;
					G_Robot_MAZE_X = 0;
					G_Robot_MAZE_Y = 0;
					G_Robot_Direction = 0;
					G_MAZE_Explored[G_Gool_X][G_Gool_Y] = 0;

					Motor_trapezoid_PID(0, 1000, 1000, 5000, 24 + 90);
					while (G_MAZE_Explored[G_Gool_X][G_Gool_Y] == 0) {
						if (Failsafe_Flag() == 1) {
							break;
						}
						Robot_Maze_Suction_Action();
						//Robot_Maze_Pass_Action();
						G_MAZE_Explored[G_Robot_MAZE_X][G_Robot_MAZE_Y] = 1;
					}
					Maze_Save();

					//Maze_Unkown_ALL_ModeSet();

					G_Gool_X = 0;
					G_Gool_Y = 0;
					G_MAZE_Explored[G_Gool_X][G_Gool_Y] = 0;
					Maze_Step_Calculate();
					while (G_MAZE_Explored[G_Gool_X][G_Gool_Y] == 0) {
						if (Failsafe_Flag() == 1) {
							break;
						}
						Robot_Maze_Suction_Action();
						//Robot_Maze_Pass_Action();
						G_MAZE_Explored[G_Robot_MAZE_X][G_Robot_MAZE_Y] = 1;
					}
					Motor_Stop();
					Suction_Stop();
					if (Failsafe_Flag() == 0) {
						Maze_Save();
					} else {
						Failsafe_Flag_OFF();
					}

					Motor_Setup();
					Motor_Stop();
					if (Failsafe_Flag() == 0) {
						Maze_Save();
					} else {
						Failsafe_Flag_OFF();
					}
					Motor_Free();
					LED_Reset();
					Encorder_count_reset();
				}
			} else if (Encorder_number_out() == 4) {		//吸引探索 +エセ全面
				if (Sensor_Enter() == 1) {
					Buzzer_Enter();
					Sensor_Start();

					Motor_Setup();
					Motor_Stop();

					Suction_Start(35);

					G_Gool_X = MAZE_GOOL_X;
					G_Gool_Y = MAZE_GOOL_Y;
					G_Robot_MAZE_X = 0;
					G_Robot_MAZE_Y = 0;
					G_Robot_Direction = 0;
					G_MAZE_Explored[G_Gool_X][G_Gool_Y] = 0;

					Motor_trapezoid_PID(0, 1000, 1000, 5000, 24 + 90);
					while (G_MAZE_Explored[G_Gool_X][G_Gool_Y] == 0) {
						if (Failsafe_Flag() == 1) {
							break;
						}
						Robot_Maze_Suction_Action();
						//Robot_Maze_Pass_Action();
						G_MAZE_Explored[G_Robot_MAZE_X][G_Robot_MAZE_Y] = 1;
					}
					Maze_Save();

					Maze_Unkown_ALL_ModeSet();

					G_Gool_X = 0;
					G_Gool_Y = 0;
					G_MAZE_Explored[G_Gool_X][G_Gool_Y] = 0;
					Maze_Step_Calculate();
					while (G_MAZE_Explored[G_Gool_X][G_Gool_Y] == 0) {
						if (Failsafe_Flag() == 1) {
							break;
						}
						Robot_Maze_Suction_Action();
						//Robot_Maze_Pass_Action();
						G_MAZE_Explored[G_Robot_MAZE_X][G_Robot_MAZE_Y] = 1;
					}
					Motor_Stop();
					Suction_Stop();
					if (Failsafe_Flag() == 0) {
						Maze_Save();
					} else {
						Failsafe_Flag_OFF();
					}

					Motor_Setup();
					Motor_Stop();
					if (Failsafe_Flag() == 0) {
						Maze_Save();
					} else {
						Failsafe_Flag_OFF();
					}
					Motor_Free();
					LED_Reset();
					Encorder_count_reset();

				}
			} else if (Encorder_number_out() == 5) {		//吸引探索
				if (Sensor_Enter() == 1) {
					Buzzer_Enter();
					Sensor_Start();

					Motor_Setup();
					Motor_Stop();

					Suction_Start(35);

					G_Gool_X = MAZE_GOOL_X;
					G_Gool_Y = MAZE_GOOL_Y;
					G_Robot_MAZE_X = 0;
					G_Robot_MAZE_Y = 0;
					G_Robot_Direction = 0;
					G_MAZE_Explored[G_Gool_X][G_Gool_Y] = 0;

					Motor_trapezoid_PID(0, 1000, 1000, 5000, 24 + 90);
					while (G_MAZE_Explored[G_Gool_X][G_Gool_Y] == 0) {
						if (Failsafe_Flag() == 1) {
							break;
						}
						Robot_Maze_Suction_Action();
						//Robot_Maze_Pass_Action();
						G_MAZE_Explored[G_Robot_MAZE_X][G_Robot_MAZE_Y] = 1;
					}
					Maze_Save();

					//Maze_Unkown_ALL_ModeSet();

					G_Gool_X = 0;
					G_Gool_Y = 0;
					G_MAZE_Explored[G_Gool_X][G_Gool_Y] = 0;
					Maze_Step_Calculate();
					while (G_MAZE_Explored[G_Gool_X][G_Gool_Y] == 0) {
						if (Failsafe_Flag() == 1) {
							break;
						}
						Robot_Maze_Suction_Action();
						//Robot_Maze_Pass_Action();
						G_MAZE_Explored[G_Robot_MAZE_X][G_Robot_MAZE_Y] = 1;
					}
					Motor_Stop();
					Suction_Stop();
					if (Failsafe_Flag() == 0) {
						Maze_Save();
					} else {
						Failsafe_Flag_OFF();
					}

					Motor_Setup();
					Motor_Stop();
					if (Failsafe_Flag() == 0) {
						Maze_Save();
						HAL_Delay(2000);

						Motor_Setup();
						Motor_Stop();
						Short_NANAME_Move2000(5000, 15000);
						Motor_Free();
						LED_Reset();
						HAL_Delay(500);
						Encorder_count_reset();

					} else {
						Failsafe_Flag_OFF();
					}

					Motor_Free();
					LED_Reset();
					Encorder_count_reset();

				}
			} else if (Encorder_number_out() == 6) {
				if (Sensor_Enter() == 1) {
					Buzzer_Enter();
					Sensor_Start();

					Motor_Setup();
					Motor_Stop();

					Suction_Start(35);

					G_Gool_X = MAZE_GOOL_X;
					G_Gool_Y = MAZE_GOOL_Y;
					G_Robot_MAZE_X = 0;
					G_Robot_MAZE_Y = 0;
					G_Robot_Direction = 0;
					G_MAZE_Explored[G_Gool_X][G_Gool_Y] = 0;

					Motor_trapezoid_PID(0, 1000, 1000, 5000, 24 + 90);
					while (G_MAZE_Explored[G_Gool_X][G_Gool_Y] == 0) {
						if (Failsafe_Flag() == 1) {
							break;
						}
						//Robot_Maze_Suction_Action();
						Robot_Maze_Pass_Action();
						G_MAZE_Explored[G_Robot_MAZE_X][G_Robot_MAZE_Y] = 1;
					}
					Maze_Save();

					//Maze_Unkown_ALL_ModeSet();

					G_Gool_X = 0;
					G_Gool_Y = 0;
					G_MAZE_Explored[G_Gool_X][G_Gool_Y] = 0;
					Maze_Step_Calculate();
					while (G_MAZE_Explored[G_Gool_X][G_Gool_Y] == 0) {
						if (Failsafe_Flag() == 1) {
							break;
						}
						//Robot_Maze_Suction_Action();
						Robot_Maze_Pass_Action();
						G_MAZE_Explored[G_Robot_MAZE_X][G_Robot_MAZE_Y] = 1;
					}
					Motor_Stop();
					Suction_Stop();
					if (Failsafe_Flag() == 0) {
						Maze_Save();
					} else {
						Failsafe_Flag_OFF();
					}

					Motor_Setup();
					Motor_Stop();
					if (Failsafe_Flag() == 0) {
						Maze_Save();
						HAL_Delay(2000);

						Motor_Setup();
						Motor_Stop();
						Short_NANAME_Move2000(6000, 15000);
						Motor_Free();
						LED_Reset();
						HAL_Delay(500);
						Encorder_count_reset();

					} else {
						Failsafe_Flag_OFF();
					}

					Motor_Free();
					LED_Reset();
					Encorder_count_reset();

				}
			} else if (Encorder_number_out() == 7) {		//Dijkstra誘導 未知壁探索
				if (Sensor_Enter() == 1) {
					Buzzer_Enter();
					Sensor_Start();

					Motor_Setup();
					Motor_Stop();

					Suction_Start(35);

					G_Gool_X = MAZE_GOOL_X;
					G_Gool_Y = MAZE_GOOL_Y;
					G_Robot_MAZE_X = 0;
					G_Robot_MAZE_Y = 0;
					G_Robot_Direction = 0;
					G_MAZE_Explored[G_Gool_X][G_Gool_Y] = 0;

					//往路: 通常の反応探索でスタート→ゴール
					Motor_trapezoid_PID(0, 1000, 1000, 5000, 24 + 90);
					while (G_MAZE_Explored[G_Gool_X][G_Gool_Y] == 0) {
						if (Failsafe_Flag() == 1) {
							break;
						}
						Robot_Maze_Pass_Action();
						G_MAZE_Explored[G_Robot_MAZE_X][G_Robot_MAZE_Y] = 1;
					}
					if (Failsafe_Flag() == 0) {
						Maze_Save();
					}

					/* スタート→ゴール固定方向でDijkstra経路を計算し、経路上の
					 * 未確認の壁を現在位置から直接見に行く。Dijkstraの再計算は
					 * 毎回ではなく、ゴール到達直後(この時点)とUターンが
					 * 発生した時だけ行う。1つの壁を確認できてUターンもして
					 * いなければ、同じ経路データのまま次の未知壁を探す
					 * (Maze_Unknown_Wall_Scan()は壁の確認状況をその都度
					 * ライブ判定するので、再計算しなくても正しく次を返せる) */
					int need_recompute = 1;
					while (Failsafe_Flag() == 0) {
						if (need_recompute == 1) {
							G_Gool_X = MAZE_GOOL_X;
							G_Gool_Y = MAZE_GOOL_Y;
							Maze_Dijkstra_Calculation();
							need_recompute = 0;
						}

						int found = Maze_Unknown_Wall_Scan();
						if (found == 0) {
							break;
						}

						Maze_Unknown_Target_ModeSet(G_Unknown_Target_X,
								G_Unknown_Target_Y);
						Maze_Step_Calculate();
						G_Just_UTurned = 0;
						int sub_steps = 0;
						while ((Maze_Unknown_Wall_Still_Unknown() == 1)
								&& (sub_steps < MAX_STEP)) {
							if (Failsafe_Flag() == 1) {
								break;
							}
							Robot_Maze_Pass_Action();
							G_MAZE_Explored[G_Robot_MAZE_X][G_Robot_MAZE_Y] = 1;
							sub_steps++;
							if (G_Just_UTurned == 1) {
								break;
							}
						}
						if ((G_Just_UTurned == 1) || (sub_steps >= MAX_STEP)) {
							//Uターンした、または目標に辿り着けなかった場合は
							//次のループ先頭で経路を再計算する
							need_recompute = 1;
						}
						Maze_Unkown_ALL_ModeOFF();
						if (Failsafe_Flag() == 0) {
							Maze_Save();
						}
					}

					//確定後: スタートへ戻る
					if (Failsafe_Flag() == 0) {
						G_Gool_X = 0;
						G_Gool_Y = 0;
						G_MAZE_Explored[0][0] = 0;
						Maze_Step_Calculate();
						while (G_MAZE_Explored[0][0] == 0) {
							if (Failsafe_Flag() == 1) {
								break;
							}
							Robot_Maze_Pass_Action();
							G_MAZE_Explored[G_Robot_MAZE_X][G_Robot_MAZE_Y] = 1;
						}
					}

					Motor_Stop();
					Suction_Stop();
					if (Failsafe_Flag() == 0) {
						Maze_Save();
					} else {
						Failsafe_Flag_OFF();
					}

					Motor_Setup();
					Motor_Stop();
					if (Failsafe_Flag() == 0) {
						Maze_Save();
						HAL_Delay(2000);

						Motor_Setup();
						Motor_Stop();
						Short_Dijkstra_Move2000(6000, 20000);
						Motor_Free();
						LED_Reset();
						HAL_Delay(500);
						Encorder_count_reset();

					} else {
						Failsafe_Flag_OFF();
					}

					Motor_Free();
					LED_Reset();
					Encorder_count_reset();

				}
			}
		} else if (Encorder_mode_out() == 1) {
			if (Encorder_number_out() == 1) {		//2m/s
				if (Sensor_Enter() == 1) {
					Buzzer_Enter();
					Sensor_Start();

					Motor_Setup();
					Motor_Stop();
					Short_NANAME_Move2000(6000, 15000);
					Motor_Free();
					LED_Reset();
					HAL_Delay(500);
					Encorder_count_reset();
				}
			} else if (Encorder_number_out() == 2) {
				if (Sensor_Enter() == 1) {
					Buzzer_Enter();
					Sensor_Start();

					Motor_Setup();
					Motor_Stop();
					Short_NANAME_Move2000(6000, 20000);
					Motor_Free();
					LED_Reset();
					HAL_Delay(500);
					Encorder_count_reset();
				}
			} else if (Encorder_number_out() == 3) {//dijk
				if (Sensor_Enter() == 1) {
					Buzzer_Enter();
					Sensor_Start();

					Motor_Setup();
					Motor_Stop();
					Short_Dijkstra_Move2000(6000, 20000);
					Motor_Free();
					LED_Reset();
					HAL_Delay(500);
					Encorder_count_reset();
				}
			} else if (Encorder_number_out() == 4) {
				if (Sensor_Enter() == 1) {
					Buzzer_Enter();
					Sensor_Start();

					Motor_Setup();
					Motor_Stop();
					Short_NANAME_Move2000(6000, 25000);
					Motor_Free();
					LED_Reset();
					HAL_Delay(500);
					Encorder_count_reset();
				}
			} else if (Encorder_number_out() == 5) {
				if (Sensor_Enter() == 1) {
					Buzzer_Enter();
					Sensor_Start();

					Motor_Setup();
					Motor_Stop();
					Short_NANAME_Move2000(6000, 30000);
					Motor_Free();
					LED_Reset();
					HAL_Delay(500);
					Encorder_count_reset();
				}
			} else if (Encorder_number_out() == 6) {
				if (Sensor_Enter() == 1) {
					Buzzer_Enter();
					Sensor_Start();

					Motor_Setup();
					Motor_Stop();
					Short_NANAME_Move2400(6000, 15000);
					Motor_Free();
					LED_Reset();
					HAL_Delay(500);
					Encorder_count_reset();
				}
			} else if (Encorder_number_out() == 7) {
				if (Sensor_Enter() == 1) {
					Buzzer_Enter();
					Sensor_Start();

					Motor_Setup();
					Motor_Stop();
					Short_NANAME_Move2400(6000, 20000);
					Motor_Free();
					LED_Reset();
					HAL_Delay(500);
					Encorder_count_reset();
				}
			} else if (Encorder_number_out() == 8) {
				if (Sensor_Enter() == 1) {
					Buzzer_Enter();
					Sensor_Start();

					Motor_Setup();
					Motor_Stop();
					Short_NANAME_Move2400(6000, 23000);
					Motor_Free();
					LED_Reset();
					HAL_Delay(500);
					Encorder_count_reset();
				}
			} else if (Encorder_number_out() == 9) {
				if (Sensor_Enter() == 1) {
					Buzzer_Enter();
					Sensor_Start();

					Motor_Setup();
					Motor_Stop();
					Short_NANAME_Move2700(5000, 20000);
					Motor_Free();
					LED_Reset();
					HAL_Delay(500);
					Encorder_count_reset();
				}
			}
		} else if (Encorder_mode_out() == 2) {

		} else if (Encorder_mode_out() == 3) {
			if (Encorder_number_out() == 1) {		//2m/s
				if (Sensor_Enter() == 1) {
					Buzzer_Enter();
					Sensor_Start();

					Motor_Setup();
					Motor_Stop();
					Short_NANAME_Move2000(2000, 20000);
					Motor_Free();
					LED_Reset();
					HAL_Delay(500);
					Encorder_count_reset();
				}
			} else if (Encorder_number_out() == 2) {		//
				if (Sensor_Enter() == 1) {
					Buzzer_Enter();
					Sensor_Start();

					Motor_Setup();
					Motor_Stop();
					Short_NANAME_Move2400(2400, 20000);
					Motor_Free();
					LED_Reset();
					HAL_Delay(500);
					Encorder_count_reset();
				}
			} else if (Encorder_number_out() == 3) {		//
				if (Sensor_Enter() == 1) {
					Buzzer_Enter();
					Sensor_Start();

					Motor_Setup();
					Motor_Stop();
					Short_NANAME_Move2700(2700, 20000);
					Motor_Free();
					LED_Reset();
					HAL_Delay(500);
					Encorder_count_reset();
				}
			}
		} else if (Encorder_mode_out() == 4) {		//基本調整
			if (Encorder_number_out() == 0) {		//センサ
				Wall_search_LED();
//								__HAL_TIM_SET_COMPARE(&htim2, TIM_CHANNEL_1, 35);
//								__HAL_TIM_SET_AUTORELOAD(&htim2, 100);
//								HAL_TIM_PWM_Start(&htim2, TIM_CHANNEL_1);
				//Suction_Start(35);
//				printf("FL = %4d //", g_sensor_av[0]);
//				printf(" L = %4d //", g_sensor_av[2]);
//				printf(" R = %4d //", g_sensor_av[1]);
//				printf("FR = %4d //", g_sensor_av[3]);
				printf("FL = %4d //", g_sensor_av10[0]);
				printf(" L = %4d //", g_sensor_av10[2]);
				printf(" R = %4d //", g_sensor_av10[1]);
				printf("FR = %4d //", g_sensor_av10[3]);
//				printf("FL = %4d //", g_sensor[0][0]);
//				printf(" L = %4d //", g_sensor[2][0]);
//				printf(" R = %4d //", g_sensor[1][0]);
//				printf("FR = %4d //", g_sensor[3][0]);
				printf("BATT = %.2f//", g_V_batt);
				printf("GyroZ = %.3f\n\r", read_NoiseCut_gyro_z());
			} else if (Encorder_number_out() == 1) {		//直進
				if (Sensor_Enter() == 1) {
					Buzzer_Enter();
					Sensor_Start();
					///
					Motor_Setup();
					Suction_Start(35);
					LOG_get_start();
					//					Motor_trapezoid_PID(0, 2000, 2000, 60000, 24);
					//					Motor_trapezoid_PID(2000, 2000, 0, 35000, 90);
					//Motor_Multistage_PID(0, 7000, 0, 25000, 180 * 9);
					//Motor_trapezoid_PID(0, 3000, 0, 20000, 180 * 9);
					//Motor_trapezoid_Asymmetric_PID(0, 4000, 0, 23000, 180 * 9);
					Motor_trapezoid_PID(0, 3000, 0, 10000, 180*8);
					Motor_Stop();
					Motor_Stop();
					Motor_Stop();
					Suction_Stop();
					LOG_get_end();
					///
					//Motor_trapezoid_PID(0, 6000, 0, 50000, 180 * 4);
					Encorder_count_reset();
				}
			} else if (Encorder_number_out() == 2) {
				if (Sensor_Enter() == 1) {
					Buzzer_Enter();
					Sensor_Start();
					///
					Motor_Setup();
					Suction_Start(35);
					LOG_get_start();
					//					for (int i = 0; i < 20; i++) {
					//						Motor_trapezoid_Turn(90, 600, 20000);
					//						Motor_Stop();
					//					}
					Motor_trapezoid_Turn(180, 1000, 30000);
					//Motor_trapezoid_Turn(3600, 600, 20000);
					///
					Motor_Stop();
					Suction_Stop();
					LOG_get_end();
					Encorder_count_reset();
				}
			} else if (Encorder_number_out() == 3) {
				if (Sensor_Enter() == 1) {
					Buzzer_Enter();
					Sensor_Start();
					//
					Motor_Setup();
					LOG_get_start();
					Motor_trapezoid_PID(0, 500, 500, 5000, 90 + 180 + 20);
					Motor_Sula_COS(500, 90, 700, 10000);
					Motor_trapezoid(500, 500, 0, 5000, 180 + 25);
					Motor_Stop();
					LOG_get_end();
					//
					Encorder_count_reset();
				}
			} else if (Encorder_number_out() == 4) {		//斜め
				if (Sensor_Enter() == 1) {
					Buzzer_Enter();
					Sensor_Start();
					Suction_Start(70);
					Motor_Setup();
					//Motor_NANAME_PID(0, 2000, 0, 5000, 127.3 * 6);
					Motor_NANAME_PID(0, 5000, 0, 20000, 127.3 * 6);
					Motor_Stop();
					Suction_Stop();
					Encorder_count_reset();
				}
			} else if (Encorder_number_out() == 5) {
				if (Sensor_Enter() == 1) {
					Buzzer_Enter();
					Sensor_Start();
					__HAL_TIM_SET_COMPARE(&htim2, TIM_CHANNEL_1, 90);
					__HAL_TIM_SET_AUTORELOAD(&htim2, 100);
					HAL_TIM_PWM_Start(&htim2, TIM_CHANNEL_1);
					while (1) {
						if (Sensor_Enter() == 1) {
							break;
						}
					}
					HAL_TIM_PWM_Stop(&htim2, TIM_CHANNEL_1);

				}
			} else if (Encorder_number_out() == 6) {		//壁合わせ
				if (Sensor_Enter() == 1) {
					Buzzer_Enter();
					Sensor_Start();

					Motor_Setup();
					Suction_Start(35);
					Motor_Robot_Alignment();
					Motor_Stop();
					Suction_Stop();
					Encorder_count_reset();
				}
			} else if (Encorder_number_out() == 7) {		//
				if (Sensor_Enter() == 1) {
					Buzzer_Enter();
					Sensor_Start();

					LOG_print();
					HAL_Delay(1000);

				}
			}
		} else if (Encorder_mode_out() == 5) {		//1m/s
			if (Encorder_number_out() == 0) {
				if (Sensor_Enter() == 1) {
					Buzzer_Enter();
					Sensor_Start();

					Motor_Setup();
					Suction_Start(35);

					HAL_Delay(1000);
					LOG_get_start();
					Motor_trapezoid_PID(0, 1000, 1000, 8000, 90 + 180);
					//Motor_trapezoid_PID(1000, 1000, 1000, 15000, 15);
					Motor_Sula_ST(1000, 1000, 1000, 15000, 15);
					Motor_Sula_COS(1000, 90, 1640, 60000);
					Motor_trapezoid(1000, 1000, 1000, 15000, 50);
					Motor_trapezoid(1000, 1000, 0, 15000, 180);

					Motor_Stop();

					HAL_Delay(500);
					Suction_Stop();
					LOG_get_end();

					Encorder_count_reset();

				}
			} else if (Encorder_number_out() == 1) {		//90
				if (Sensor_Enter() == 1) {
					Buzzer_Enter();
					Sensor_Start();

					Motor_Setup();
					Suction_Start(35);
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

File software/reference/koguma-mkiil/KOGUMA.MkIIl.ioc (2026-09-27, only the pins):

Mcu.UserName=STM32F446RETx
PA0-WKUP.GPIO_Label=WallLED_34
PA0-WKUP.Signal=GPIO_Output
PA1.GPIO_Label=WallLED_12
PA1.Signal=GPIO_Output
PA10.Signal=GPIO_Output
PA11.Signal=GPIO_Output
PA12.Signal=GPIO_Output
PA13.Signal=SYS_JTMS-SWDIO
PA14.Signal=SYS_JTCK-SWCLK
PA15.GPIO_Label=ENCO_R_NSS
PA15.Signal=GPIO_Output
PA2.Signal=USART2_TX
PA3.GPIO_Label=LEDF1
PA3.Signal=GPIO_Output
PA4.GPIO_Label=ICM_NSS
PA4.Signal=GPIO_Output
PA5.Signal=SPI1_SCK
PA6.Signal=SPI1_MISO
PA7.Signal=SPI1_MOSI
PB0.Signal=SPI3_MOSI
PB1.Signal=ADCx_IN9
PB12.GPIO_Label=LED1
PB12.Signal=GPIO_Output
PB13.GPIO_Label=LED2
PB13.Signal=GPIO_Output
PB14.GPIO_Label=LED3
PB14.Signal=GPIO_Output
PB15.GPIO_Label=LED4
PB15.Signal=GPIO_Output
PB4.GPIO_Label=LED5
PB4.Signal=GPIO_Output
PB5.GPIO_Label=LED6
PB5.Signal=GPIO_Output
PB6.GPIO_Label=LED7
PB6.Signal=GPIO_Output
PB7.GPIO_Label=LED8
PB7.Signal=GPIO_Output
PB8.Signal=S_TIM2_CH1_ETR
PB9.Signal=S_TIM4_CH4
PC0.Signal=ADCx_IN10
PC1.Signal=ADCx_IN11
PC10.Signal=SPI3_SCK
PC11.Signal=SPI3_MISO
PC13.GPIO_Label=LEDF4
PC13.Signal=GPIO_Output
PC14-OSC32_IN.GPIO_Label=LEDF3
PC14-OSC32_IN.Signal=GPIO_Output
PC15-OSC32_OUT.GPIO_Label=LEDF2
PC15-OSC32_OUT.Signal=GPIO_Output
PC2.Signal=ADCx_IN12
PC3.Signal=ADCx_IN13
PC5.GPIO_Label=ENCO_L_NSS
PC5.Signal=GPIO_Output
PC6.Signal=S_TIM3_CH1
PC7.Signal=S_TIM3_CH2
PC8.Signal=S_TIM3_CH3
PC9.Signal=S_TIM3_CH4
PH0-OSC_IN.Signal=RCC_OSC_IN
PH1-OSC_OUT.Signal=RCC_OSC_OUT

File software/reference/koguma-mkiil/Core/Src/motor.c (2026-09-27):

/*
 * motor.c
 *
 *  Created on: Jun 12, 2025
 *      Author: akihi
 */

#include "motor.h"
#include "tim.h"
#include "math.h"
#include "PL_encoder.h"
#include "PL_timer.h"
#include "Define.h"
#include "lsm6dsr.h"
#include "PL_sensor.h"
#include "Wallsensor.h"
#include "Maze.h"
#include "UI.h"
#include "stdlib.h"

float G_Robot_speed = 0;

float G_Motor_X = 0;
float G_Motor_Ac = 0;
float G_Motor_V_Target = 0;

float G_Motor_Angle = 0;
float G_Motor_W_Ac = 0;
float G_Motor_W_Target = 0;

int G_Motor_Flag = 0;
float G_Motor_Count = 0;

float Motor_PWM_L, Motor_PWM_R;

float Enc_error = 0;
float Enc_Old_error = 0;
float Enc_Sigma_error = 0;
float Enc_Delta_error = 0;

float Gyro_error = 0;
float Gyro_Old_error = 0;
float Gyro_Sigma_error = 0;
float Gyro_Delta_error = 0;

float Ksp = 0.25; //0.8
float Ksi = 0.0015; //0.002
float Ksd = 0.01; //0.5

float Ksp_Fun = 0.23; //0.5
float Ksi_Fun = 0.0015; //0.005
float Ksd_Fun = 0.1; //0.01

float Ksp_AT = 0.3; //0.3
float Ksi_AT = 0.003; ////
float Ksd_AT = 0.01;

float Ktp = 0.7; //
float Kti = 0.01; //
float Ktd = 0.001; //

float Ktp_sula = 0.7; //0.12
float Kti_sula = 0.005; //0.06
float Ktd_sula = 0.001; //0.01

float Ktp_sula_20 = 1.2; //0.12
float Kti_sula_20 = 0.02; //0.06
float Ktd_sula_20 = 0.01; //0.01

float Ktp_sula_24 = 1.4; //0.12
float Kti_sula_24 = 0.02; //0.06
float Ktd_sula_24 = 0.01; //0.01

float Motor_FB_ST = 0;
float Motor_FB_Turn = 0;
float Motor_FF_ST = 0;
float Motor_FF_Turn = 0;

float Motor_Voltage_L = 0;
float Motor_Voltage_R = 0;

int PID_Mode = 0;
int Turn_Mode = 0;
int Fun_Flag = 0;

int Sula_Flag = 0;

float Alignment_TIME = 0.5;

int Flont_th = 130; //310

float Cut_R = 80;
float Cut_L = 80;

float Cut_R_NA = 150;
float Cut_L_NA = 150;

float Run_Voltage;

float Aff = 0.65;
float Bff = 0.50;

float FF_offset = 15.0;

void Motor_Setup() {
	HAL_TIM_PWM_Start(&htim3, TIM_CHANNEL_1);
	HAL_TIM_PWM_Start(&htim3, TIM_CHANNEL_2);
	HAL_TIM_PWM_Start(&htim3, TIM_CHANNEL_3);
	HAL_TIM_PWM_Start(&htim3, TIM_CHANNEL_4);
	Enc_Sigma_error = 0;
	Gyro_Sigma_error = 0;
}

void Motor_Setup_Voltage() {
	Run_Voltage = g_V_batt;
}

void Motor_Stop() {
	G_Motor_Flag = 1;
	PID_Mode = 0;
	G_Motor_V_Target = 0;
	G_Motor_Ac = 0;
	Enc_Sigma_error = 0;
	Gyro_Sigma_error = 0;
//	Motor_PWM_L = 0;
//	Motor_PWM_R = 0;
	wait_ms(50);
	Motor_PWM_L = 0;
	Motor_PWM_R = 0;
	Enc_Sigma_error = 0;
	Gyro_Sigma_error = 0;
	G_Motor_Flag = 0;

}

void Suction_Start(int duty) {
	Fun_Flag = 1;
	if (duty == 50) {
		Sula_Flag = 1;
	} else if (duty >= 70) {
		Sula_Flag = 2;
	} else if (duty <= 20) {
		Fun_Flag = 0;
	}
	HAL_TIM_PWM_Start(&htim2, TIM_CHANNEL_1);
	__HAL_TIM_SET_AUTORELOAD(&htim2, 100);
	duty = duty * (15.8 / Run_Voltage);
	for (int i = 1; duty > i; i += 1) {
		__HAL_TIM_SET_COMPARE(&htim2, TIM_CHANNEL_1, i);
		HAL_Delay(10);
	}

	HAL_Delay(500);
}

void Fun_Flag_OFF() {
	Fun_Flag = 0;
}

void Suction_change(int duty) {
	duty = duty * (15.8 / Run_Voltage);
	__HAL_TIM_SET_COMPARE(&htim2, TIM_CHANNEL_1, duty);
}

void Suction_Stop() {
	HAL_TIM_PWM_Stop(&htim2, TIM_CHANNEL_1);
	Sula_Flag = 0;
	Fun_Flag = 0;
}

float cal_turnV(float W) {
	float TurnV = ((float) TIREBETWEEN * PI / 360) * W;
	return TurnV;
}

void Motor_PWM_Generate() { //MP6550モーター出力

	Motor_Voltage_L = Motor_PWM_L * (REFERENCE_V / Run_Voltage);
	Motor_Voltage_R = Motor_PWM_R * (REFERENCE_V / Run_Voltage);

	if (Motor_Voltage_L > 200) {
		Motor_Voltage_L = 200;
	} else if (Motor_Voltage_L < -200) {
		Motor_Voltage_L = -200;
	}

	if (Motor_Voltage_R > 200) {
		Motor_Voltage_R = 200;
	} else if (Motor_Voltage_R < -200) {
		Motor_Voltage_R = -200;
	}

	if (Motor_Voltage_L > 0) {
		__HAL_TIM_SET_COMPARE(&htim3, TIM_CHANNEL_1, 200 - Motor_Voltage_L);
		__HAL_TIM_SET_COMPARE(&htim3, TIM_CHANNEL_2, 200);
	} else {
		__HAL_TIM_SET_COMPARE(&htim3, TIM_CHANNEL_1, 200);
		__HAL_TIM_SET_COMPARE(&htim3, TIM_CHANNEL_2,
				200 - fabs(Motor_Voltage_L));
	}
	if (Motor_Voltage_R > 0) {
		__HAL_TIM_SET_COMPARE(&htim3, TIM_CHANNEL_3, 200 - Motor_Voltage_R);
		__HAL_TIM_SET_COMPARE(&htim3, TIM_CHANNEL_4, 200);
	} else {
		__HAL_TIM_SET_COMPARE(&htim3, TIM_CHANNEL_3, 200);
		__HAL_TIM_SET_COMPARE(&htim3, TIM_CHANNEL_4,
				200 - fabs(Motor_Voltage_R));
	}
}

void Motor_Free() {
	G_Motor_V_Target = 0;
	G_Motor_Ac = 0;
	Suction_Stop();
	HAL_TIM_PWM_Stop(&htim3, TIM_CHANNEL_1);
	HAL_TIM_PWM_Stop(&htim3, TIM_CHANNEL_2);
	HAL_TIM_PWM_Stop(&htim3, TIM_CHANNEL_3);
	HAL_TIM_PWM_Stop(&htim3, TIM_CHANNEL_4);
}

void Motor_Back() {
	G_Motor_Flag = 5;
	G_Motor_V_Target = -300;
	G_Motor_Ac = 0;
	wait_ms(250);
	Enc_Sigma_error = 0;
	Motor_PWM_L = 0;
	Motor_PWM_R = 0;
	G_Motor_Flag = 0;
}

void Motor_Speed_PID_ST(int V, int Ac) { // mm/s

	float T = ((TIREDIAMETER / 2000) * ROBOT_M * (Ac / 1000)) / (2 * GEARRATIO)
			* Aff;
	//float w = 0;
	float w = (60 * GEARRATIO * (V / 1000)) / (2 * PI * (TIREDIAMETER / 2000))
			* Bff;
	Motor_FF_ST = (((MOTORR * T) / KT) + (w * KE)) / Run_Voltage * 200.0;

	if (V > 1) {
		Motor_FF_ST += FF_offset;
	} else if (V < -1) {
		Motor_FF_ST -= FF_offset;
	}

	G_Robot_speed = ((G_Tire_Speed_L + G_Tire_Speed_R) / 2); //)+ (read_average_acc_x()*0.01/2)

	Enc_error = V - G_Robot_speed;
	Enc_Delta_error = Enc_error - Enc_Old_error;
	Enc_Sigma_error += Enc_error;

	if (Enc_Sigma_error > 2000)
		Enc_Sigma_error = 2000;
	else if (Enc_Sigma_error < -2000)
		Enc_Sigma_error = -2000;

	if (Fun_Flag == 1) {
		Motor_FB_ST = Ksp_Fun * Enc_error + Ksi_Fun * Enc_Sigma_error
				+ Ksd_Fun * Enc_Delta_error;
	} else {
		Motor_FB_ST = (Ksp * Enc_error + Ksi * Enc_Sigma_error
				+ Ksd * Enc_Delta_error);
	}

	if (PID_Mode == 0) {
		Motor_PWM_L = Motor_FB_ST + Motor_FF_ST;
		Motor_PWM_R = Motor_FB_ST + Motor_FF_ST;
	} else if (PID_Mode == 1) {
//		if (Fun_Flag == 1) {
//			Motor_PWM_L = Motor_FF_ST + Motor_FB_ST + calWallConrol(); //
//			Motor_PWM_R = Motor_FF_ST + Motor_FB_ST - calWallConrol(); //
//		} else {
		Motor_PWM_L = Motor_FF_ST + Motor_FB_ST + calWallConrol(); //
		Motor_PWM_R = Motor_FF_ST + Motor_FB_ST - calWallConrol(); //
//		}
	} else if (PID_Mode == 2) {
		Motor_PWM_L = Motor_FB_ST + Motor_FF_ST + calWallConrol_NANAME();
		Motor_PWM_R = Motor_FB_ST + Motor_FF_ST - calWallConrol_NANAME();
	} else if (PID_Mode == 3) {
		Motor_PWM_L = calWallConrol_Flontwall_ST(); //
		Motor_PWM_R = calWallConrol_Flontwall_ST(); //
	}

	Enc_Old_error = Enc_error;

}
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

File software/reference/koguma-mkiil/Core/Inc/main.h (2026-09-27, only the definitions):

#define LEDF4_Pin GPIO_PIN_13
#define LEDF4_GPIO_Port GPIOC
#define LEDF3_Pin GPIO_PIN_14
#define LEDF3_GPIO_Port GPIOC
#define LEDF2_Pin GPIO_PIN_15
#define LEDF2_GPIO_Port GPIOC
#define WallLED_34_Pin GPIO_PIN_0
#define WallLED_34_GPIO_Port GPIOA
#define WallLED_12_Pin GPIO_PIN_1
#define WallLED_12_GPIO_Port GPIOA
#define LEDF1_Pin GPIO_PIN_3
#define LEDF1_GPIO_Port GPIOA
#define ICM_NSS_Pin GPIO_PIN_4
#define ICM_NSS_GPIO_Port GPIOA
#define ENCO_L_NSS_Pin GPIO_PIN_5
#define ENCO_L_NSS_GPIO_Port GPIOC
#define LED1_Pin GPIO_PIN_12
#define LED1_GPIO_Port GPIOB
#define LED2_Pin GPIO_PIN_13
#define LED2_GPIO_Port GPIOB
#define LED3_Pin GPIO_PIN_14
#define LED3_GPIO_Port GPIOB
#define LED4_Pin GPIO_PIN_15
#define LED4_GPIO_Port GPIOB
#define ENCO_R_NSS_Pin GPIO_PIN_15
#define ENCO_R_NSS_GPIO_Port GPIOA
#define LED5_Pin GPIO_PIN_4
#define LED5_GPIO_Port GPIOB
#define LED6_Pin GPIO_PIN_5
#define LED6_GPIO_Port GPIOB
#define LED7_Pin GPIO_PIN_6
#define LED7_GPIO_Port GPIOB
#define LED8_Pin GPIO_PIN_7
#define LED8_GPIO_Port GPIOB

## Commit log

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2026-07-27 Kick off main-board circuit design: block plan and BOM draft
    Lock in motor driver (MP6551 x2), IMU (LSM6DSRXTR), and encoder
    (AS5047P x2) choices in the overview. Add a functional-block plan and
    peripheral allocation notes for the STM32F411CEU6 main board, plus a
    BOM draft, to accelerate schematic capture in KiCad.
    [BOM.csv]
2026-07-27 Lock in wall sensor parts: LTR-209 + OSI5FU3A11C, 4 pairs
    Front-diagonal x2 and side x2. Updates ADC channel count (4) and GPIO
    count for sequenced LED drive in the main-board plan, BOM, and overview.
    [BOM.csv]
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2026-07-27 Add suction fan and confirm motor power is direct LiPo
    Motor driver (MP6551) power confirmed as direct LiPo connection, no
    regulator in between. Add suction fan block: PWM-controlled via
    low-side N-channel MOSFET (fan direction fixed, no H-bridge needed).
    Fan part and skirt/seal design are still open TODOs, including
    verifying competition rules allow suction devices.
    [BOM.csv]
2026-07-27 Select NCR321PAS as wall sensor IR LED driver
    Constant-current LED driver IC with digital PWM enable (up to 10kHz),
    adjustable output up to 250mA via external resistor. Fits the
    sequenced 4-emitter drive scheme directly from a GPIO, replacing the
    generic switching-transistor placeholder. Powered from the 3.3V rail;
    voltage margin against OSI5FU3A11C Vf + 1.4V driver overhead needs
    bench verification.
    [BOM.csv]
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2026-07-28 Restructure: hardware/kicad/main-board/ -> hardware/kicad/TORANEKO.Mk3/
    Drop the extra main-board/ nesting level; the KiCad project, its
    README, and BOM now live directly under kicad/TORANEKO.Mk3/, matching
    the actual KiCad project name. Updates cross-references in
    docs/overview.md, hardware/README.md, and hardware/kicad/README.md.
    [BOM.csv, TORANEKO.Mk3.kicad_pcb, TORANEKO.Mk3.kicad_sch]
2026-07-28 Add board outline DXF files for TORANEKO.Mk3
    Encoder, main board, and upper mounting board outlines exported from CAD for KiCad edge-cuts import.
    [エンコーダ外形.dxf, メイン基板外形.dxf, 上部固定基板外形.dxf]
2026-09-26 Add Fusion 360 full-assembly STEP export (v36)
    Claude-Session: https://claude.ai/code/session_01Cv6KpZe6NLHWQTjQMUz9Sg
    [TORANEKO.Mk3_v36.step]
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2026-09-27 Tentatively set NCR321PAS Rext to 9.1 ohm for ~100 mA peak
    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
    [BOM.csv]
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2026-09-27 Wall-sensor LED: target 180 mA (Rext 4.3 ohm), add circuit and layout notes
    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
    [BOM.csv]
2026-09-27 Wall-sensor LED: set Rext to 5.1 ohm (~155 mA) for headroom margin
    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
    [BOM.csv]
2026-09-27 Update TORANEKO.Mk3 schematic and add NCR321PASX library
    - Update main board schematic (.kicad_sch / .kicad_pro)
    - Add schematic PDF export
    - Add NCR321PASX component library (symbol/footprint/3D model)
    - Ignore KiCad local project settings (*.kicad_prl)
    [EDI2CAP.CFG, NCR321PASX.PcbLib, NCR321PASX.SchLib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]
2026-09-27 Update TORANEKO.Mk3 schematic
    - Remove LED/resistor pairs D23/R29, D24/R30 and connectors J4, J7
    - Add decoupling capacitor C24 (0.1u)
    - Re-export schematic PDF
    [TORANEKO.Mk3.kicad_sch]
2026-09-27 Add decoupling capacitors C25, C28-C30 to TORANEKO.Mk3 schematic
    - Add four 0.1u decoupling capacitors (C25, C28, C29, C30)
    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
    [TORANEKO.Mk3.kicad_sch]
2026-09-27 Add 47u bulk capacitors C10, C11 on +3.3V to TORANEKO.Mk3 schematic
    - Add two 47u capacitors (C10, C11) between +3.3V and GND
    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
    [TORANEKO.Mk3.kicad_sch]
2026-09-27 Record confirmed pin assignment and CubeMX setup for main-controller
    - PIN_REQUIREMENTS.md: pin table extracted from schematic 9a54a18 and
    differences from KOGUMA.MkIIl
    - CUBEMX_SETUP.md: clock (10MHz HSE -> 100MHz), timers, ADC, SPI, USART,
    NVIC settings for step 0
    - Mark resolved hardware TODOs; ignore CubeIDE build outputs
    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
2026-09-27 Start TORANEKO.Mk3 PCB layout; update schematic; add motor mount DXF
    - Import schematic into PCB and start board layout (.kicad_pcb)
    - Schematic: re-add LED/resistor pairs D23/R29, D24/R30 (2k) and connector J4;
    rework LED / WallLED global labels
    - Add motor mount outline DXF
    [TORANEKO.Mk3.kicad_pcb, TORANEKO.Mk3.kicad_sch, モータマウント.dxf]
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2026-09-27 Add GND symbol #PWR065 to TORANEKO.Mk3 schematic
    - Add GND power symbol (#PWR065)
    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
    [TORANEKO.Mk3.kicad_sch]
2026-09-29 Add placement guide DXFs generated from STEP (main board and encoder board)
    - 配置ガイド_メイン基板.dxf: encoder board/chip/magnet positions, part
    footprints sectioned at the board surface, overhanging parts with height
    clearance (same frame as メイン基板外形.dxf)
    - 配置ガイド_エンコーダ基板.dxf: magnet axis, AS5047P body/pads centred on
    the axis, edge-pad zones (same frame as エンコーダ外形.dxf)
    - README: how to import, KiCad coordinates of encoder boards, clearances
    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
    [配置ガイド_エンコーダ基板.dxf, 配置ガイド_メイン基板.dxf]
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2026-09-29 Continue TORANEKO.Mk3 PCB layout and schematic update
    - PCB layout progress (.kicad_pcb)
    - Schematic updates (.kicad_sch)
    - Change default via/pad size in project settings
    - Ignore KiCad local history directory (.history/)
    [TORANEKO.Mk3.kicad_pcb, TORANEKO.Mk3.kicad_sch]
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2026-09-29 Continue TORANEKO.Mk3 PCB layout; add C14 to schematic
    - Schematic: add 47u capacitor C14
    - Add preset track widths (0.1/0.3/0.5/1.0/2.0 mm) to board setup
    - Ignore KiCad autosave index (#auto_saved_files#)
    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
    [TORANEKO.Mk3.kicad_pcb, TORANEKO.Mk3.kicad_sch]
2026-09-29 Fix .gitignore: escape leading # for KiCad #auto_saved_files#
2026-09-29 Route TORANEKO.Mk3 PCB: add tracks, vias and a zone
    - Add ~1034 track segments, 155 vias and 1 copper zone
    - Update preset track widths (0.15/0.3/0.4/0.8/1.5 mm)
    - Change default pad size to 4.0 x 4.0 mm (drill 0)
    [TORANEKO.Mk3.kicad_pcb]
2026-09-29 Encoder edge footprint: shorten chip-side pads to keep 0.2mm to AS5047P, lengthen back pads
    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
2026-09-29 Continue TORANEKO.Mk3 PCB routing; relax clearances; re-export PDF
    - Routing progress: 1034 -> 1246 track segments, 155 -> 185 vias
    - Design rules: min clearance and copper-to-edge clearance 0.5 -> 0.2 mm
    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
    [TORANEKO.Mk3.kicad_pcb]
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2026-09-29 Fix capacitor values in TORANEKO.Mk3 schematic/PCB (0.1 -> 0.1u, 10 -> 10u)
    - Add missing "u" unit to two 0.1u and two 10u capacitor values
    - Sync updated values to the PCB
    [TORANEKO.Mk3.kicad_pcb, TORANEKO.Mk3.kicad_sch]
2026-09-30 Continue TORANEKO.Mk3 PCB routing; update pad geometry
    - Adjust existing tracks and add routing (1246 -> 1260 segments)
    - Update position/size of 12 pads (likely footprint update from library)
    [TORANEKO.Mk3.kicad_pcb]
2026-09-30 Continue TORANEKO.Mk3 PCB routing; refill zone
    - Rework and add tracks (1260 -> 1272 segments)
    - Refill copper zone
    [TORANEKO.Mk3.kicad_pcb]
2026-09-30 Add encoder board panel (6 boards, side tabs with mouse bites, clean solder edge)
    Generated from the main PCB by panel/make_encoder_panel.py. Each copy gets its
    own net names; clearance and connectivity checked with a script (no KiCad DRC).
    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
    [TORANEKO.Mk3_encoder_panel.kicad_pcb]
2026-09-30 Add upper fixing plate to the order panel (60 x 56.3mm)
    Rename encoder panel to TORANEKO.Mk3_panel / make_panel.py. The plate
    outline, cutouts and holes are read from 上部固定基板外形.dxf; tabs only on
    its straight edges, separated from the encoder row by a 3mm bar.
    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
    [TORANEKO.Mk3_panel.kicad_pcb]
2026-10-04 Adjust TORANEKO.Mk3 PCB routing; add panel project file
    - Move existing tracks and 14 vias; group items (no count change)
    - Default pad size back to 1.5 x 1.5 mm, drill 0.9 mm
    - Add KiCad project file for the order panel
    [TORANEKO.Mk3.kicad_pcb]
2026-10-04 Add vectorized emblem logo DXF (20mm wide, closed outlines)
    Traced from ホワイトグリント色反転ロゴ.jpg with potrace.
    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
    [ロゴ_ホワイトグリント.dxf]
2026-10-04 Panel: add logo silkscreen on the upper plate; follow moved encoder boards
    - Place ロゴ_ホワイトグリント.dxf as filled F.SilkS polygons in the lower-left
    free area of the upper plate (largest fit, 0.3mm clearance -> 7.1mm wide)
    - Update encoder board outline coordinates to the new main-board positions
    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
    [TORANEKO.Mk3_panel.kicad_pcb]
2026-10-04 Panel: rotate upper-plate logo 90 deg clockwise (now 8.0mm wide)
    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
    [TORANEKO.Mk3_panel.kicad_pcb]
2026-10-06 Shrink wall sensor THT pads to 1.5mm (drill 0.9) for edge clearance
    LED_D3.0mm pads of D7-D10, D13-D16 were 0.12-0.21mm from the sensor
    mount slots; with 1.5mm pads all are >= 0.27mm. Also clears the
    LED-to-phototransistor pad clearance violations.
    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
    [TORANEKO.Mk3.kicad_pcb]
2026-10-06 Main PCB check fixes: encoder B edge gap, via spacing, fine-pitch DRC rule
    - Move encoder board B outline down 0.05mm so U5 pads are 0.213mm from
    the edge (same as U3; was 0.163mm). Panel regenerated to match.
    - Nudge VBAT via at (102.15, 82.65) to (102.1, 82.7): hole gap 0.195 -> 0.27mm
    - Add TORANEKO.Mk3.kicad_dru allowing 0.14mm between pads of U1 (LGA-14)
    and IC6 (UFQFPN48), whose footprints are 0.15-0.18mm apart by design
    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
    [TORANEKO.Mk3.kicad_pcb, TORANEKO.Mk3_panel.kicad_pcb]
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2026-10-12 panel README: fix PCBA placement count (65)
    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
2026-10-12 Fix DRC errors: S1 locating holes to NPTH, add IC6 courtyard
    - S1 (SSSS810701) pads 4/5 were plated holes with zero annular ring;
    they are the plastic locating bosses, so make them NPTH
    - IC6 footprint had no F.CrtYd, so the fine-pitch rule in
    TORANEKO.Mk3.kicad_dru (intersectsCourtyard) never matched its pads
    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
2026-10-12 Switch firmware toolchain to CubeMX (CMake) + VS Code
    Replace the STM32CubeIDE assumptions in the main-controller docs with a
    CubeMX-generated CMake project built from VS Code, so the firmware can be
    built from the command line (CI, remote sessions). Commit Drivers/ so the
    project builds without CubeMX.
    Claude-Session: https://claude.ai/code/session_01Eg9SUiNAsN8YmHW7qZojxd
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2026-10-13 No.7: stop and compute the shortest path once no unseen walls remain
    When search_find_unknown_wall finds nothing left to check, the robot
    stops where it is and only then computes the shortest path, before
    returning to the start. Record this flow for sys/explore.c and check it
    in the PC simulation (the path computed at the stop does not change on
    the way back).
    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
2026-10-13 Fix issues found in a full review of the firmware and maze code
    - maze_map: walls are only added, never removed by a later miss (as in
    KOGUMA); the start cell's east wall is fixed like the outer walls.
    Shared maze_is_in_area / maze_direction_between replace duplicates
    - dijkstra: report the cost of the route actually returned (it could
    differ from the stored state cost) and reset it when no route exists
    - search: UNKNOWN_WALL_NO_PLAN when there is no stored plan, instead of
    looking like 'all walls checked'
    - uart: save/restore PRIMASK instead of unconditionally re-enabling
    interrupts, keep interrupts off for at most 16 bytes at a time, and
    recover from DMA errors in HAL_UART_Erro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
2026-10-14 KOGUMA_PORTING: rewrite the open log, mode and failsafe items against the latest KOGUMA
    - B: log columns, row count (1000 rows to fit next to the 32x32 maze),
    output format compatible with the KOGUMA viewer, maze dump check,
    sensor display, wall LEDs, with a RAM estimate
    - C: modes 2-10 of the latest KOGUMA, and a proposed ToraNeko mode table
    - F: failsafe checks one by one
    All items stay open until the author confirms them.
    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
2026-10-14 Add FDM auxiliary parts: suction skirt, sliders, battery holder, stand
    - skirt_slider/: suction skirt frame around the fan hole (6 screws,
    front/rear slider pads 0.5mm above the floor), plus front/rear
    sliders cut from it for use without the skirt
    - battery_holder/: holds the two 12x25x6 cells on the upper board,
    fixed by the fan-motor-mount screws; raises the cells 1.4mm because
    the STEP has them intersecting the motor mounts and motors
    - jigs/maintenance_stand/: stand that lifts the tires 3mm for bench
    tests, works with the skirt or sliders attached
    Each part has a CadQuery script, a print-oriented STL, a STEP in the
    machine STEP coordinates, and a preview image. All parts were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
2026-10-14 Tape-mount the suction skirt; add a centering plate
    - skirt_frame: drop the six screw tabs. The frame now has a 3mm top
    flange for double-sided tape, is 0.15mm shorter so its bottom stays
    at the same height once taped, and has pockets for the post screw
    heads that also locate it. slider_front/slider_rear keep the screw
    mounting.
    - jigs/centering_plate: 83.4mm square plate that fits a half-size cell
    (84mm between walls); a rim around the board outline puts the
    robot's center on the cell center.
    Claude-Session: https://claude.ai/code/session_01XrHDjKpMP1gwkoKKpPakGF
2026-10-14 Add MODES.md: operation, LED display and mode layout decided with the author
    - Select with the tires, decide with SW1, start by covering and
    releasing the front sensor (run starts 1 s later). No buzzer, so all
    signals are LEDs; mode on the middle 3 LEDs, No. on the outer 4.
    - Modes: 0 explore (all without suction: round trip, one way, unknown
    walls), 1 shortest (slowest first), 2-4 turn tests per turn speed,
    5 sensor adjustment, 6 basic adjustment, 7 settings (goal x/y,
    load maze).
    - Goal size fixed at 2x2, position entered on the robot and loaded at
    power-on. The maze starts empty at power-on, is loaded only on
    request, and is saved at the start, at a one-way goal and on
    fai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
2026-10-14 MODES: one turn-tuning mode each for exploration and shortest runs
    - Mode 2: exploration turns at search speed (slalom 90, U-turn,
    stop-and-go, plus pivot 180 and wall alignment moved from the basic
    adjustment mode).
    - Mode 3: shortest-run turns No.1-7; the turn speed set is chosen by a
    variable in the program, not by the mode.
    - Mode 4 is free. Both turn modes turn left only, like KOGUMA.
    - Mode 6 is renumbered: 0 sensor display, 1 straight, 2 diagonal,
    3 suction on, 4 output.
    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
2026-10-15 Centering plates: stronger rims and bars, longer side rims
    - Rims are 2.4 mm wide (was 1.6) and sit on a 4 mm wide, plate-thick
    base so they do not snap at the root.
    - Side rims hold the board for 15 mm (was 10).
    - Diagonal plates: rear bar 8 mm (was 6), side bar 10 mm (was 8), and
    a 20 mm triangular gusset where the two bars meet.
    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
2026-10-15 Add mode selection and robot operation (sys/mode.c, ui.c, goal.c)
    - ui.c: LED display (mode on the middle 3 LEDs, No. on the outer 4,
    goal values on LED3-7), signals (decision blink, ok, error), tire
    steps from encoder counts, debounced switch, hand detection on the
    front sensor, start wait (cover and release, run 1 s later, switch
    to reselect) and failsafe reset wait.
    - mode.c: select with the tires, decide with the switch (No.0 and
    empty numbers do nothing), keep the same mode/No. after a run, and
    run mode 0 No.1-3 (explore) and mode 7 No.2 (goal input) / No.3
    (load maze). Tire rotation during a run is forgotten before
    selecting.
    - goal.c: goal position loaded from Flash at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
2026-10-15 Add the run log and the output (sys/log.c, sys/output.c)
    - log.c: 1000 rows of the KOGUMA log columns stored as int16 in fixed
    units, recorded from the control interrupt every N periods (interval
    chosen per run in ms, CTRL_FREQ_HZ = 2000), first row on the first
    call; when full it just stops recording (the run continues) and the
    output says full=1. Printed in the KOGUMA viewer LOG format.
    - output.c: the maze in the KOGUMA viewer MAZE format (ROW/COL/LROW/LCOL
    hex, goal, unknown wall count), the shortest path the shortest run
    would take with motion names, then the run log and #DONE. Mode 7
    No.1 now calls it.
    - uart_wait_free(): wait for space in the 2 KB send buffer so the
    ~1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
2026-10-15 Add a case insert that holds the robot inside the lunch-box inner tray
    A plate sized to the inner tray's floor, with four posts under the
    board (tires float, skirt touches nothing) and L-shaped corner guides.
    The inner tray dimensions are not published anywhere, so they are
    estimated from the OSK PCR-7 lunch box (140x113 mm, 360 ml, two 145 ml
    trays) and kept as four parameters to replace with measured values.
    The script prints the side, end, corner and top clearances.
    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
2026-10-15 Encoder solder jig: clamp onto the board edge instead of M1.4 screws
    FDM cannot print the 1.1 mm self-tap holes, so the jig now holds the
    main board by the edge of the wheel cutout, which is exactly where the
    jig's outer face already was. A C-shaped jaw grips the 0.6 mm board
    from above and below, its inner face sets the chip/magnet position,
    and a stop on its rear end rests against the end of the cutout. The
    jig slides on from the cutout side; checked that neither the mounted
    jig nor the slide-in path touches the board or any part.
    Slots use zero clearance (SLOT_C = 0, CLAMP_C = 0): the 0.60 mm slot
    on the width test piece held the encoder board just right.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
2026-10-22 モードを選べるようにした（モード選択をファームウェアに入れた）
    - app.c：起動したら初期化して、mode_run_once() を繰り返す
    - ctrl/wall_ctrl.c：4 つの壁センサの値、壁のあり・なし、前センサの手（しきい値は仮）
    - sys/failsafe.c：止まっているかを覚えておく（異常を見つける部分はステップ9）
    - ctrl/run.c：走る部分はステップ7まで仮。頼まれたらフェイルセーフで止まる
    - モード5 No.1 センサ値の表示（sys/sensor_view.c、KOGUMA と同じ書式、壁の有無を LED に）。スタート待ちをしない
    - タイヤ 1 段ぶんの量を 8192 カウントに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
2026-10-22 エンコーダの歪みの表を入れた。直したあとに残るずれも出すようにした
    - config/encoder_correction.h：実機で測った表（1.0V 2 回、2.0V 1 回の平均）。
    直す前のずれは左 約 730 カウント（16°）、右 約 370 カウント（8°）。
    速さを変えても同じ形なので、回り方の波ではなくエンコーダのずれ
    - sys/encoder_cal.c：今の表で直した角度のずれ（after correction p-p）も出す。
    表を入れたあとに No.6 を回すと、効き目がわかる
    - drv/encoder.c：表で直した角度を返す関数を足した（歪みを測るときに使う）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
2026-10-28 Make the case insert D-shaped and size it from a photo of the lunch-box tray
    Measured the tray floor on a photo using the 40 x 64 mm board as scale
    (about 65 x 82 mm, R20 on the rounded side, R5 on the straight side) and
    made the plate slightly smaller: 64 x 80 mm, R22 / R6. The old guess
    (56 x 98 mm) would not have fit. Moved the centre cut-out and the FRONT
    mark back inside the shorter plate.
    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
2026-10-28 Shrink the case insert to 52 x 74 mm and shift the robot to the straight side
    The 64 x 80 mm plate did not go into the lunch-box tray; it sat on the
    rim. Re-measured on that photo using the plate as scale (rim outside
    about 63 x 85 mm, floor about 54 x 76 mm) and went smaller still.
    At this width the corner guides do not fit in the large rounded
    corners with the robot centred, so the robot sits 3 mm toward the
    straight side and the guides are clipped to the plate outline.
    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
2026-11-02 参照用の KOGUMA のコードを最新（fa64b58、2026-10-27）にする
    - software/reference/koguma-mkiil を KOGUMA.MkIIl の master fa64b58 に入れ替えた
    （KOGUMA.MkII/・.github/・logs/ の実機ログ（README.md 以外）は除外）
    - Maze.c が ShortParam.c と sinf/cosf を使うようになったので、
    maze-test.yml の行き止まり潰しの検証に ShortParam.c と -lm を足した
    - reference/README.md と KOGUMA_PORTING.md のコミットの記載を直した
    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
2026-11-03 右の壁の目標を走行中の値に、壁切れの位置を測った値にし、前壁補正の平均も出す
    2026-11-03 の探索の走行ログと RESULT から：
    - 横壁制御の右の目標 942 → 815（左右に壁がある直進で、左が約 42mm のとき右は 805〜830 だった）。
    使う下限も 650 → 570（目標の約 7 割）
    - WALL_EDGE_POSITION_MM 70 → 55（2 回見つかって平均 54.9mm。まだ WALL_EDGE_ENABLE 0 のまま回数を集める）
    - モード7 No.1 の Search: front correction に平均を足した。記録するのは ±10mm の上限をかける前の量にした
    （上限で止めた値だと、本当はいくつずれていたかわ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
2026-11-03 最短走行 No.4・5 を、ターンごとの速さ（800・600mm/s）で、吸引して走るようにした
    - sys/shortest.c：ターンは、そのターンの速さ（config/turn_params.h の *_SPEED_MM_S）で曲がる。
    直進の終わりの速さは、経路の終わりまで先を見て決める（speed_limit_ahead_mm_s()）。
    上げきれないとき・ターンが続くとき・その先で遅くしきれないとき・ゴールで止まるときは遅く曲がる
    - No.4・5 は吸引 5.0V で走る（走り出す前に 0.5 秒で上げて 0.5 秒待つ。終わったら止める）
    - config/run_params.h：No.4 を直進 1000・斜め 800mm/s・4000mm/s²、No.5 を直進 15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
2026-11-03 test_turn --slip：実機で足した前距離・後距離を、空回りの式（係数 1 つ）で説明できるか調べる
    「床の上の速さ ＝ 速さ ×（1 − 係数 × 横向きの加速度）」の係数 1 つ（1000mm/s² あたり 1.04%）で、
    6 つのターンで実機で足した分が平均 1.5mm のずれで合い（空回りなしでは 6.5mm）、大回り 180° の幅
    （781.0deg/s のとき実機 82mm・式 82.5mm）も合った。速さごとの足す分の表も出す。
    ファームウェアは変えていない。
    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
2026-11-03 test/Makefile の説明に test_turn --slip を足す
    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
2026-11-04 最短走行の縦横の直進で、壁切れのずれを測る（まだ直さない。FAST_WALL_EDGE_ENABLE 0）
    - run_fast_straight に、直進を始める位置（うしろの区画の境目から何 mm 先か）を渡すようにし、
    探索と同じやり方で横の壁の切れ目を見つけ、いちばん近い「区画の入口 + 切れ目の位置（左 53.5・右 56.0mm）」とのずれを求める
    - モード7 No.1 に、1 回ごとの左右・速さ・ずれを出す（Shortest: wall edge、fedge の行）
    - 速さでずれが変わるかを見てから、直すのを入れる
    - test_maze [10]：仮の機体で、教えた「始める位置」が本当の位置と合って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
2026-11-10 最短走行は、ゴールに入ってからもう 1 区画進んで、その区画のまん中で止まる（作者の案）
    ゴールは 2×2 なので、経路の終わり（ゴールの最初の区画のまん中）から同じ向きにもう 1 区画進んでも、まだゴールの中にいる。
    経路の最後に 1 区画の直進を足して（最後が直進なら 1 区画長くして）、直進で入ってもターンで入っても、
    止まるところを同じ「ゴールの 2 つ目の区画のまん中」にした（sys/shortest.c の extend_into_goal()）。
    次の区画がゴールの外・あいだに壁があるときは足さない（今までどおり）。
    test_maze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
2026-11-10 最短走行の吸引の電圧を No. ごとに決められるようにする（No.4〜6）。モード3 の吸う電圧も決められるようにする
    - config/run_params.h に SHORTEST4_SUCTION_V・SHORTEST5_SUCTION_V・SHORTEST6_SUCTION_V（今は 3 つとも 5.0V）
    - config/turn_params.h に TURN_TEST_SUCTION_V（今は 5.0V）。ターンは、走るときと同じ電圧で合わせる
    - sys/suction.c に suction_ramp_up_to(電圧) を足した（suction_ramp_up() は SUCTION_VOLTAGE_V で、これを呼ぶ）
    - README のモード一覧と MODES.md を直した
    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
2026-11-11 最短走行のあと、ゴールで入ってきた向きを向いて位置を覚え、そこから探索して帰れるようにする（モード0 No.5・6）。モード7 のゴール・迷路呼び出しを No.14・15 へ
    - 最短走行（モード1 No.1〜6）：ゴールで止まったら、止まった区画の壁を見て、前壁合わせをしながら入ってきた向きを向き、
    止まった区画・入ってきた向き・見た壁を覚える（sys/shortest.c の turn_back_at_goal()）
    - モード0 No.5・6：覚えた位置から、置き直さずに未知壁探索をしてスタートへ戻る（No.6 は既知区間加速あり。
    sys/explore.c の explore_run_from_go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
2026-11-11 ゴールから始める探索（モード0 No.5・6）を消す
    作者が「使わない」と決めたので消した。最短走行がゴールで入ってきた向きを向き、止まった位置を覚える動きは残す
    （今は覚えるだけ。型は shortest.h の shortest_end_pose_t にした）。
    explore_run_from_goal()・run_search_start_at_center()・覚えた位置を忘れる仕組み・test_maze の [10b] を消し、
    README のモード一覧・MODES.md・mode.c の先頭のコメントを直した。
    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
2026-11-11 ターンの組 3（ゆるいターン 1200mm/s・きついターン 1000mm/s）と、それで走る最短走行 No.7 を作る
    - config/turn_params.h：組 3（T1200_…）。ゆるいターン 3 つ（大回り 90°・斜め入り 45°・斜め出 45°）は 1200mm/s・角加速度 57600deg/s²
    （test_turn --calc の値。横向きの加速度は約 17500〜18400mm/s²）。実機で足す分は、まだ組 2 の値のまま
    - ctrl/run.c：fast_turn_values_set3()。きついターン 4 つは組 2 の値をそのまま使う。run_fast_set_turn_set(3) で選ぶ
    - 最短走行 No.7（sys/shortest.c、config/run_params.h の SHORTEST7_*）：直進・斜めは No.6 と同じ、吸引 5.0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
2026-11-12 最短走行の直進の加速度に、吸引の強さから出したグリップの上限を入れる
    - sys/shortest.c：直進・斜めの直進の加速度を、決めた加速度と grip_accel_limit_mm_s2() の小さいほうにする（減速も同じ）。
    上限 = 3600 ×（26g + 吸引の力）÷ 26g × 0.8。吸引の力は、その No. の吸引の電圧から、2026-11-10 に測った表で出す
    （吸引なし 約 2880、5V 約 17300、7V 約 21700mm/s²）
    - config/run_params.h：GRIP_NO_SUCTION_SLIP_MM_S2・GRIP_MARGIN・SUCTION_FORCE_1V_G〜7V_G。config/robot_params.h：ROBOT_MASS_G
    - 今の値で変わるのは No.3（3000 → 約 2880mm/s²）だけ。探索・調整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

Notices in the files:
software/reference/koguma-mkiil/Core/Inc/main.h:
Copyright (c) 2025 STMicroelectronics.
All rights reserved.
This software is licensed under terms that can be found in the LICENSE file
